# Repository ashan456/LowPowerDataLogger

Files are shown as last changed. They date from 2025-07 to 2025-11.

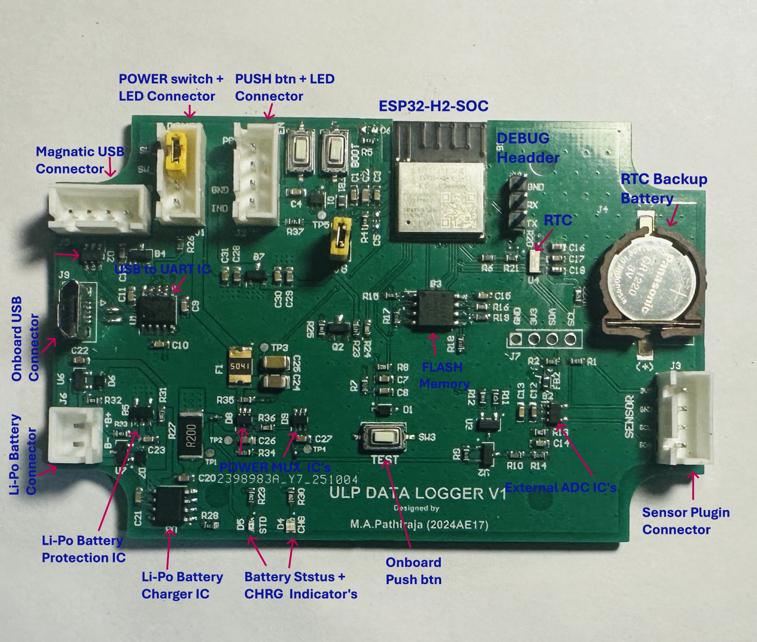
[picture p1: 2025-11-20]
Hardware_Design/Images/Prototype/New folder/PCB Marked.JPG

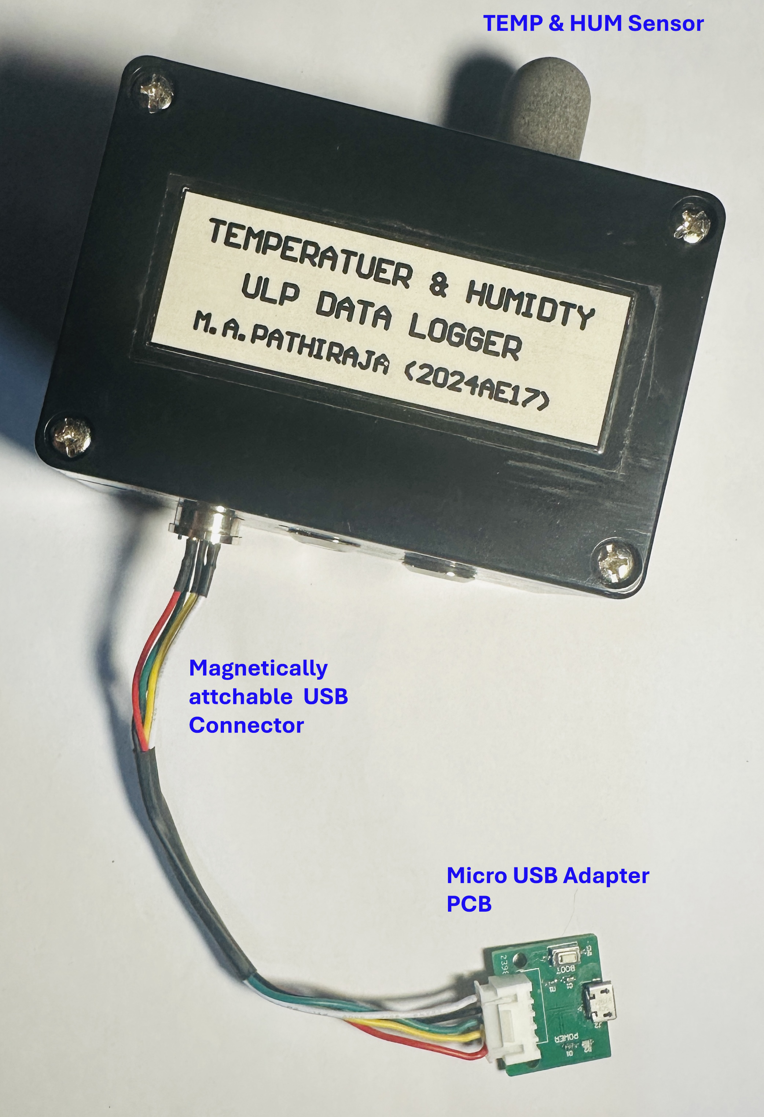
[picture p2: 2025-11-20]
Hardware_Design/Images/Prototype/New folder/Overview.png

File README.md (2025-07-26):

# LowPowerDataLogger
Development of an Ultralow-Power, Battery-Operated Data Logger, specifically tailored for long-term outdoor temperature monitoring in field experiments. 

1.	Introduction

A data logger is an electronic device designed to record measurements over time, storing them for later analysis. This project focuses on the Development of an Ultralow-Power, Battery-Operated Data Logger, specifically tailored for long-term outdoor temperature monitoring in field experiments. By leveraging energy-efficient microcontrollers, precision temperature sensors, and optimized power-management techniques such as deep-sleep modes, lower clock speeds, and low-leakage voltage regulators, the system achieves exceptionally low quiescent currents. Powered by a compact rechargeable or non-rechargeable battery pack and enhanced with a smart power-budget algorithm, the logger can operate autonomously for months without human intervention. Its rugged enclosure, waterproof sealing, and minimal maintenance requirements make it ideal for remote deployments in harsh environments.

2.	Targets

The main targets to be achieved to complete the project are,
• Accurately measure and record ambient temperature.
• Measure and record relative humidity.
• Operate autonomously for at least one month on a single battery charge.
• Buffer and organize time-stamped data in non-volatile local storage.
• Monitor battery voltage and gracefully shut down before depletion.
• Withstand outdoor conditions with a waterproof, rugged enclosure.

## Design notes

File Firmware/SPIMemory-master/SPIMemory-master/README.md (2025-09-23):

# SPIMemory  







## Arduino library for Flash & FRAM Memory Chips (SPI based only)
<sup> Download the latest stable release from [here](https://github.com/Marzogh/SPIMemory/releases/latest). Please report any bugs in [issues](https://github.com/Marzogh/SPIMemory/issues/new).</sup>

This Arduino library is for use with flash and FRAM memory chips that communicate using the SPI protocol. In its current form it supports identifying the flash/FRAM chip and its various features; automatic address allocation and management; writing and reading a number of different types of data, ranging from 8-bit to 32-bit (signed and unsigned) values, floats, Strings, arrays of bytes/chars and structs to and from various locations; sector, block and chip erase; and powering down for low power operation.

<hr>

### IDE Compatibility (actually tested with)

- Arduino IDE v1.5.x
- Arduino IDE v1.6.x
- Arduino IDE v1.8.x

<hr>

### Platform compatibility

| Micro controllers | Dev boards tested with | Notes |
| --- | --- | ----- |
| ATmega328P | Arduino Uno, Arduino Micro, <br> Arduino Fio, Arduino Nano | - |
| ATmega32u4 | Arduino Leonardo, Arduino Fio v3 | - |
| ATmega2560 | Arduino Mega | - |
| ATSAMD21G18 (ARM Cortex M0+) | Adafruit Feather M0, <br> Adafruit Feather M0 Express, <br> Adafruit ItsyBitsy M0 Express | - |
| AT91SAM3X8E (ARM Cortex M3) | Arduino Due | - |
| nRF52832 (ARM Cortex M4F) | Adafruit nRF52 Feather | - |
| ATSAMD51J19 (ARM Cortex M4) | Adafruit Metro M4 | - |
| STM32F091RCT6 | Nucleo-F091RC | |
| STM32L0 | Nucleo-L031K6 | |
| ESP8266 | Adafruit ESP8266 Feather, <br> Sparkfun ESP8266 Thing | - |
| ESP32 | Adafruit ESP32 Feather, <br> Sparkfun ESP32 Thing | Onboard flash memory. Refer to footnote<sup>£</sup> below. |
| Simblee | Sparkfun Simblee | - |

<sup>£ </sup><sub> ESP32 boards usually have an SPI Flash already attached to their default SS pin, so the user has to explicitly declare the `ChipSelect` pin being used with the constructor</sub>

<hr>

### Flash memory compatibility - Actually tested with

| Manufacturer | Flash IC | Notes |
| --- | --- | ----- |
| Winbond | W25Q16BV <br> W25Q64FV <br> W25Q64JV <br> W25Q80BV <br> W25Q256FV | Should work with the W25QXXXBV, W25QXXXFV & <br> W25QXXXJV families |
| Microchip | SST25VF064C <br> SST26VF016B <br> SST26VF032B <br> SST26VF064B | Should work with the SST25 & SST26 families |
| Cypress/Spansion | S25FL032P <br> S25FL116K <br> S25FL127S | Should work with the S25FL family |
| ON Semiconductor | LE25U40CMC |  |
| AMIC| A25L512A0 |  |
| Micron| M25P40 |  |
| Adesto| AT25SF041 |  |
| Macronix| MX25L4005 <br> MX25L4005 |  |
| Giga devices| GD25Q16C | (Used on the Adafruit ItsyBitsy M0 Express) |

##### Should work with any flash memory that is compatible with the SFDP standard as defined in JESD216B

<hr>

### FRAM memory compatibility - Actually tested with

| Manufacturer | Flash IC | Notes |
| --- | --- | ----- |
| Cypress/Spansion | FM25W256 | Should work with the FM25W family |

<hr>

### Installation

#### Option 1
- Open the Arduino IDE.
- Go to Sketch > Include Library > Manage libraries.
- Search for SPIMemory.
- Install the latest version.

#### Option 2
- Click on the 'Clone or download' button above the list of files on this <a href = "https://github.com/Marzogh/SPIMemory/tree/master"> page </a>.
- Select Download ZIP. A .zip file will download to your computer.
- Unzip the archive and rename resulting folder to 'SPIMemory'
- Move the folder to your libraries folder (~/sketches/libraries)

### Usage

#### SPIFlash

- The library is called by declaring the```SPIFlash flash(csPin*)``` constructor where 'flash' can be replaced by a user constructor of choice and 'csPin' is the Chip Select pin for the flash module.

    <sub>* Optional. Do not include csPin if using the default slave select pin for your board.</sub>
- Every version of the library >= v3.0.0 supports the ability to use any of multiple SPI interfaces (if your micro-controller supports them). Switching to use another SPI interface is done by calling ```SPIFlash flash(csPin, &SPI1);``` (or &SPI2 and so on), instead of ```SPIFlash flash(csPin)```.

    <sub>* NOTE: This is currently only supported on the SAMD and STM32 architectures.</sub>
- An alternate version ```SPIFlash flash (SPIPinsArray)``` of the constructor can be used (only with ESP32 board as of now) to enable the use of custom SPI pins. ```SPIPinsArray``` has to be a 4 element array containing the custom SPI pin numbers (as signed integers - int8_t) in the following order - sck, miso, mosi, ss.
- Also make sure to include ```flash.begin(CHIPSIZE*)``` in ```void setup()```. This enables the library to detect the type of flash chip installed and load the right parameters.

    <sub>* Optional</sub>

##### Note on SFDP discovery
As of v3.2.1, SFDP parameter discovery is an user controlled option. To get the library to work with SFDP compatible flash memory chips that are not officially supported by the library, the user must uncomment '//#define USES_SFDP' in 'SPIMemory.h'.

##### Notes on Address overflow and Error checking
- The library has Address overflow enabled by default - i.e. if the last address read/written from/to,  in any function, is 0xFFFFF then, the next address read/written from/to is 0x00000. This can be disabled by uncommenting ```#define DISABLEOVERFLOW``` in SPIMemory.h. (Address overflow only works for Read / Write functions. Erase functions erase only a set number of blocks/sectors irrespective of overflow.)

- All write functions have Error checking turned on by default - i.e. every byte written to the flash memory will be checked against the data stored on the Arduino. Users who require greater write speeds can disable this function by setting an optional last 'errorCheck' argument in any write function to NOERRCHK - For eg. call the function ```writeByte(address, *data_buffer, NOERRCHK)``` instead of ```writeByte(address, *data_buffer)```.

#### SPIFram <sup>^</sup>

- The library is called by declaring the```SPIFram fram(csPin*)``` constructor where 'fram' can be replaced by a user constructor of choice and 'csPin' is the Chip Select pin for the fram module.

    <sub>* Optional. Do not include csPin if using the default slave select pin for your board.</sub>
- Every version of the library >= v3.0.0 supports the ability to use any of multiple SPI interfaces (if your micro-controller supports them). Switching to use another SPI interface is done by calling ```SPIFram fram(csPin, &SPI1);``` (or &SPI2 and so on), instead of ```SPIFram fram(csPin)```.

    <sub>* NOTE: This is currently only officially supported on the SAMD and STM32 architectures.</sub>
- Also make sure to include ```fram.begin(CHIPSIZE*)``` in ```void setup()```. This enables the library to detect the type of fram chip installed and load the right parameters.

<sup>^</sup> <sub> Currently in BETA. The methods in SPIFram are not final and subject to change over the next few revisions.</sub>

The library enables the following functions:
<hr>

#### Non-Read/Write functions
<hr>

###### `begin(_chipsize)`

###### `setClock(clockSpeed)`

###### `error(_verbosity)`

###### `getManID()`

###### `getJEDECID()`

###### `getUniqueID()`

###### `getAddress(sizeOfData)`

###### `sizeofStr()`

###### `getCapacity()`

###### `getMaxPage()`

###### `functionRunTime()`

<hr>

##### Read commands
<hr>
<sub>
All read commands take a last boolean argument 'fastRead'. This argument defaults to FALSE, but when set to TRUE carries out the Fast Read instruction so data can be read at up to the memory's maximum frequency.
</sub>

<sub>
All read commands only take a 32-bit address variable instead of the optional 16-bit page number & 8-bit offset variables in previous versions of the library (< v3.0.0)
</sub>

###### `readAnything(address, value)`

###### `readByte(address)`

###### `readChar(address)`

###### `readWord(address)`

###### `readShort(address)`

###### `readULong(address)`

###### `readLong(address)`

###### `readFloat(address)`

###### `readStr(address, outputStr)`

###### `readAnything(address, value)`
<hr>

##### Write commands
<hr>
<sub>
All write commands take a boolean last argument 'errorCheck'. This argument defaults to TRUE, but when set to FALSE will more than double the writing speed. This however comes at the cost of checking for writing errors. Use with care.
</sub>

<sub> All write commands only take a 32-bit address variable instead of the optional 16-bit page number & 8-bit offset variables in previous versions of the library (< v3.0.0) </sub>

###### `writeByte(address, data)`

###### `writeChar(address, data)`

###### `writeWord(address, data)`

###### `writeShort(address, data)`

###### `writeULong(address, data)`

###### `writeLong(address, data)`

###### `writeFloat(address, data)`

###### `writeStr(address, data)`

###### `writeAnything(address, value)`

<hr>

##### Continuous read/write commands
<sub>
All write commands take a boolean last argument 'errorCheck'. This argument defaults to TRUE, but when set to FALSE will more than double the writing speed. This however comes at the cost of checking for writing errors. Use with care.
</sub>
<hr>

###### `readByteArray(address, *data_buffer, bufferSize)`

###### `writeByteArray(address, *data_buffer, bufferSize)`

###### `readCharArray(address, *data_buffer, bufferSize)`

###### `writeCharArray(address, *data_buffer, bufferSize)`

<hr>

##### Erase commands
<sub>
All erase commands only take a 32-bit address variable instead of the optional 16-bit page number & 8-bit offset variables in previous versions of the library (< v3.0.0)
</sub>
<hr>

###### `eraseSector(address)`

###### `eraseBlock32K(address)`

###### `eraseBlock64K(address)`

###### `eraseChip()`

###### `eraseSection(address, sizeOfData)`

<hr>

##### Suspend/Resume commands
<hr>

###### `suspendProg()`

###### `resumeProg()`
<hr>

##### Power operation commands
<hr>

###### `powerDown()`

###### `powerUp()`

<hr>

##### Error codes explained

Note: If you are unable to fix the error/s, please raise an issue [here](http://www.github.com/Marzogh/SPIMemory/issues) with the details of your flash chip and what you were doing when this error occurred. **Please follow the issue template that show up at the link**

| Error code  | Explanation |
| :---: | --- |
| **0x00** | Function executed successfully |
| **0x01** | `*constructor_of_choice*.begin()` was not called in `void setup()` |
| **0x02** | Unable to identify chip. <br> Is this chip officially supported? |
| **0x03** | Unable to identify capacity. <br> Is this chip officially supported? <br> If not, please define a `CAPACITY` constant and include it in `flash.begin(CAPACITY)`. |
| **0x04** | Chip is busy. Make sure all pins have been connected properly. |
| **0x05** | Page overflow has been disabled and the address called exceeds the memory |
| **0x06** | Unable to Enable Writing to chip. <br> Please make sure the HOLD & WRITEPROTECT pins are pulled up to VCC. |
| **0x07** | This sector already contains data. <br> Please make sure the sectors being written to are erased. |
| **0x08** | You are running low on RAM. <br> Please optimise your code for better RAM usage |
| **0x09** | Unable to suspend/resume operation. <br> Please raise an issue. |
| **0x0A** | Write Function has failed errorcheck. <br> Please raise an issue. |
| **0x0B** | Check your wiring. Flash chip is non-responsive. |
| **0x0C** | This function is not supported by the memory hardware. |
| **0x0D** | Unable to enable 4-byte addressing. <br> Please raise an issue. |
| **0x0E** | Unable to disable 4-byte addressing. <br> Please raise an issue. |
| **0x0F** | The chip is currently powered down. |
| **0x10** | The Flash chip does not support SFDP. |
| **0x11** | Unable to read Erase Parameters from chip. <br> Reverting to library defaults. |
| **0x12** | Unable to read erase times from flash memory. <br> Reverting to library defaults. |
| **0x13** | Unable to read program times from flash memory. <br> Reverting to library defaults. |
| **0x14** | No Chip Select pin defined in the custom SPI Array. <br> Refer to section about Constructor for information on how to use custom SPI pins. |
| **0xFE** | Unknown error. <br> Please raise an issue. |

<hr>

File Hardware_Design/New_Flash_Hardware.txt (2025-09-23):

WP,HOLD short - Pull to  High via 10K
CS - Pull to  High via 10K
CLK - Pull Down via 100K
DI -  Pull Down via 100K
DO -  Pull Down via 100K

battery voltage resitiro devider - Replace with ulp ADC

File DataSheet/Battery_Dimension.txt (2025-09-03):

Length = 50mm
Width = 34mm
Height = 7 mm

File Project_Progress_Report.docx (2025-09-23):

# Development of an ultralow-power battery-operated data logger

Project Progress Report –

## Hardware

• Component Sourcing: 98%

• Ultra Low Battery Hardware: 100% (Complete)

• Working Prototype: 100% (Complete)

• PCB Design: 10%

## Firmware

• Accurate Temp/Humidity Measurement: 100% (Complete)

• Data Storage on Flash (Little FS): 100% (Complete)

• Low Power Sleep Mode (4-7uA sleep, 16-22uA active): 100% (Complete)

• Data Retrieval: 100% (Complete)

• Device Config Without Reflash: 50%

• Fail Safe (RTC/Watchdog/Battery-Based Interval): 20%

Finalized Block Diagram –

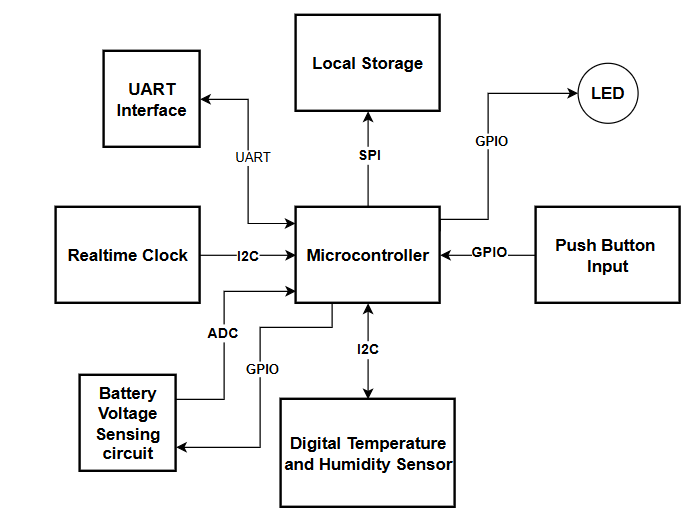
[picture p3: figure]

Figure 1: Block Diagram of the System

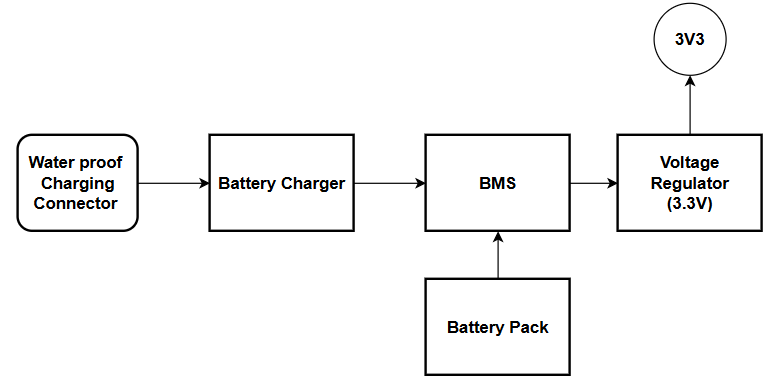
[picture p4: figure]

Figure 2: Block Diagram of the power supply

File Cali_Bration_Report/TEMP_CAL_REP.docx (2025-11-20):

Temperature and Humidity Sensor Calibration

The temperature calibration of the SHT45 sensor was performed at an ISO/IEC 17025 accredited laboratory (IMC, Sri Lanka). Five calibration points were evaluated across the operating range of the sensor. The reference thermometer uncertainty is incorporated into the expanded uncertainty reported by the lab.

- Device Under Test (DUT): Temperature and Humidity Logger (SHT45 Sensos)
- Reference Instrument: Digital thermometer with Pt1000 sensor (Reg No:(7424)362-0191A)
- Measurement Range: Temperature :10°C to 50°C , Humidity: 55.00 %RH and 72.00 %RH

Measurement Data (Provided by Laboratory):

i)Temperature Measurement

Reference Temperature (°C) | Device Reading (°C) | Correction (°C) | Expanded Uncertainty, U (°C)
9.79 | 10.33 | −0.54 | ±0.20
19.60 | 20.06 | −0.46 | ±0.20
29.67 | 29.91 | −0.24 | ±0.20
39.90 | 40.35 | −0.45 | ±0.20
49.89 | 50.28 | −0.39 | ±0.20

ii) Relative Humidity Measurement

Reference Humidity (%) | Device Reading (%) | Correction (%) | Expanded Uncertainty, U (%)
55.00 | 53.21 | 1.79 | ±3
72.00 | 73.15 | -1.15 | ±3

i) Temperature calibration

A linear regression was performed to relate Device temperature reading to true reference temperature,

Performed linear regression to model:

T_(Corrected) =m ×T_(device) +b

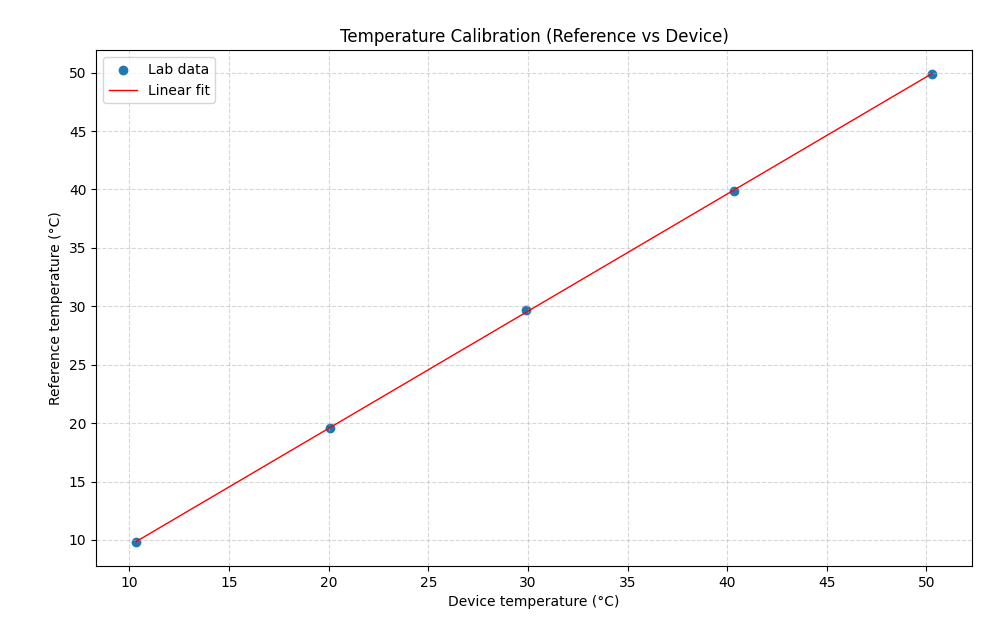
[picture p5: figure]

Best-fit parameters:

- Slope (a): 1.00302
- Offset (b): -0.5073 °C
- Coefficient of determination (R²): 0.9999

Residual statistics

- Mean residual: 0 °C
- Standard deviation: 0.101167 °C
- Maximum absolute residual: 0.176835 °C

Uncertainty Calculation

The lab guarantees the reference temperature is correct within ±0.20 °C with 95% confidence. [multiplying the combined standard uncertainty by a coverage factor k = 2]

Therefore, Lab Reference standard uncertainty = 0.10°C

Calibration model Uncertainty (S.D of residuals) = 0.101167 °C

The Lab reference uncertainty and model fitting uncertainty are independent.

Combine them using root-sum-of-squares (RSS):

u_c =√(u_(lab)^2 +u_(modle)^2)

Where, u_(lab) = 0.1 °C , u_(modle) =0.101167 °C

Substitute values:
u_c =0.1414 °C

Therefore, uncertainty expanded (k=2 for 95% confidence) U=2 ×0.1414 °C=0.2828°C

Fitted model with uncertainty:

T_(Corrected) (°C)=(1.00302 ×T_(device) (°C)-0.5073 ) ±0.28°C

ii) Relative Humidity calibration

The accredited laboratory provided only two calibration points,

Since only two points were provided, a 2-point linear calibration was derived as ,

RH_(Corrected) =m ×RH_(device) +b

The slope m and intercept b were calculated directly using,

m=(R_(2-) R_1)/(D_2 -D_1)=0.8525

b=R_1 -m×D_1 =9.6354

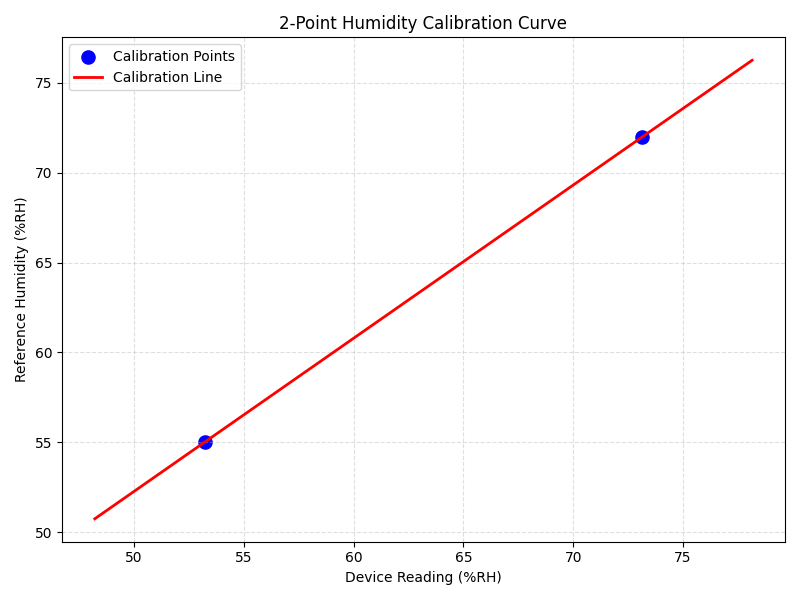
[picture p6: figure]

Uncertainty Calculation

The lab guarantees the reference relative humidity is correct within ±3 %RH with 95% confidence. [multiplying the combined standard uncertainty by a coverage factor k = 2]

Therefore, Lab Reference standard uncertainty = 1.5 % RH

The fitted model itself contributes no statistically estimable additional uncertainty (u_fit ≈ 0 %RH, artefact of 2-point line).

Therefore , Calibration model Uncertainty (S.D of residuals) = 0 % RH

The Lab reference uncertainty and model fitting uncertainty are independent.

Combine them using root-sum-of-squares (RSS):

u_c =√(u_(lab)^2 +u_(modle)^2)

Where, u_(lab) = 1.5 % RH , u_(modle) =0 % RH

Substitute values:
u_c =1.5 % RH

Therefore, uncertainty expanded (k=2 for 95% confidence) U=2 ×1.5 % RH=3 % RH

Fitted model with uncertainty:

RH_(Corrected) (%RH)=(0.8525×RH_(device) (%RH)+9.6354) ±3% RH

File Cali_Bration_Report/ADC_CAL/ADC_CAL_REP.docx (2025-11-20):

Battery Voltage Measurement - ADC Calibration

The MCP3021 (12-bit) ADC was used to measure the battery voltage in the custom ESP32-H2 data logger hardware.

- Device Under Test (DUT): Custom PCB with ESP32-H2 and MCP3021 ADC
- Reference Instrument: Digital Multimeter (DMM, ±25mV at range (9.999V))
- Voltage Source: Bench DC power supply
- Measurement Range: 3300–4300 mV

Measurement Data:

Multiple voltages measured (Supplied from Bench power supply in range 3.3V to 4.3V) simultaneously by the DMM and ADC (uncalibrated firmware output).

Table 1.1: Reference Voltage and ADC computed Voltage in mV

Reference Voltage (mV) [±25 mV] | ADC Measurement (mV)
3302 | 3317
3401 | 3409
3501 | 3506
3601 | 3606
3701 | 3703
3804 | 3802
3903 | 3899
4001 | 3999
4102 | 4098
4201 | 4201
4304 | 4294

Linear Regression Model

A linear model was fitted to relate the ADC reading (input) to the true reference voltage,

V_(Calibrated) =a ×V_(ADC) +b

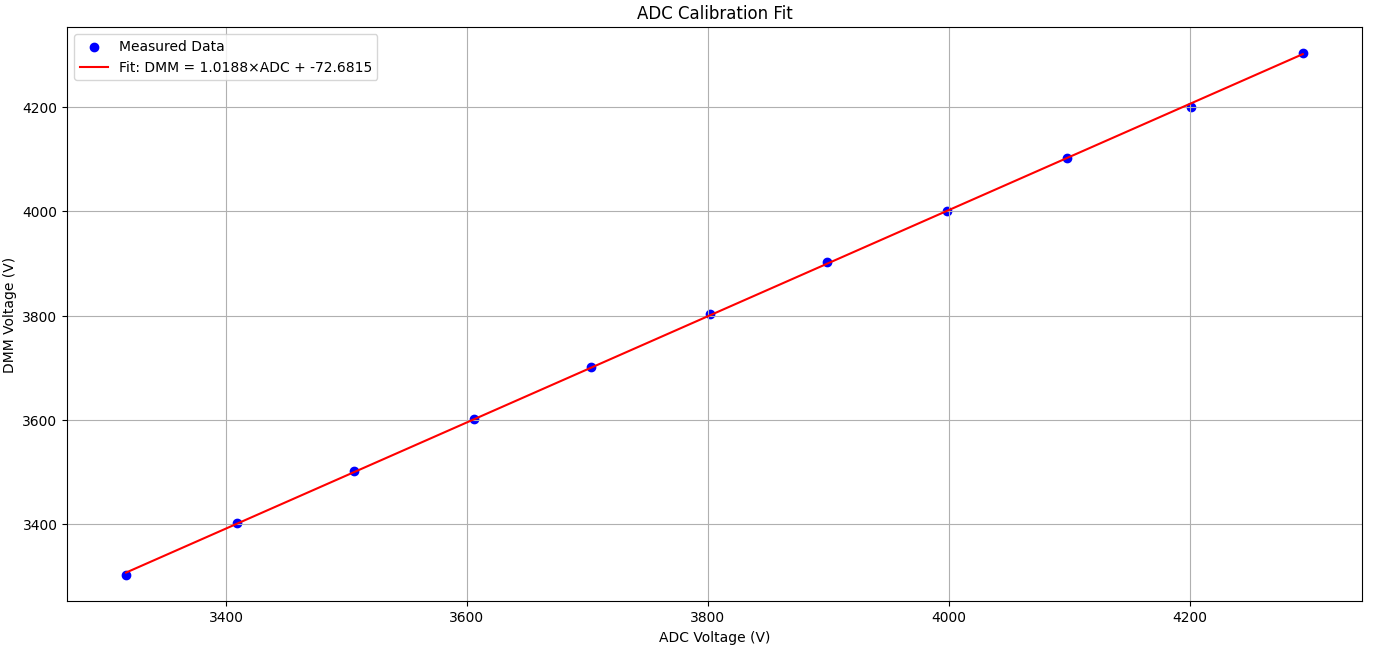
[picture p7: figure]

Best-fit parameters:

- Slope (a): 1.0188
- Offset (b): –72.6815 mV
- Coefficient of determination (R²): 0.999917

Residual statistics

- Mean residual: ≈ 4.5×10^(-13) mV → effectively 0 mV
- Standard deviation: 2.89 mV
- Maximum absolute residual: 6.3 mV (at 4201 mV point)

Note: -

After calibration, the ADC readings follow the model with max error ≈ ±6.3 mV, but the absolute accuracy is limited by the DMM’s ±25 mV.

Fitted model with uncertainty:

V_(Calibrated) (mV)=1.0188 ×V_(ADC) (mV)-72.6815 ±25 mV

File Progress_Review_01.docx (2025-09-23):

Hardware:

- Component Sourcing - 90%
- Ultra Low Battery Powered Hardware Construction – 100% - Completed
- Working Prototype – 100% Completed

Firmware :

- Measure Temperature and Humidity accurately – 100%
- Store Data on Local Storage (Uses Little FS File system on Flash memory) – 100%
- Low power sleep Mode (Timer Interrupt) – 100% ( Sleep :- 4 - 7uA) and (Active :- 16 - 22 uA average)
- Retrieve stored data from the device – 100%
- Device Configuration without re-flashing firmware – 50%
- Fail safe (RTC not worked, Watchdog , Change interval based on battery power) – 20%

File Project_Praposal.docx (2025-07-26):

Development of an ultralow-power battery-operated data logger

M.A. Pathiraja (2024AE17)

2025.07.26

# 1. Introduction

Accurate environmental monitoring underpins climate science, ecological investigation, and agricultural optimization; however, extant data‐logging instruments are often prohibitively expensive, necessitate frequent battery replacement, and exhibit limited resilience in adverse outdoor settings. This proposal outlines the Development of an Ultralow-Power, Battery-Operated Data Logger for sustained field deployment. The architecture integrates an energy-efficient microcontroller, a factory-calibrated temperature and humidity sensors, and firmware optimized through deep-sleep operation, clock scaling, and adaptive duty cycling to minimize energy consumption. A smart power-budget algorithm, in concert with either rechargeable (Li-ion) or primary cell chemistries and ultra-low-leakage voltage regulation, facilitates autonomous operation exceeding one month on a single charge. Recorded data are preserved in onboard nonvolatile memory with precise timestamps, while the IP65-rated enclosure with sealed connectors and corrosion-resistant push button to ensure mechanical robustness. Collectively, these design choices yield a maintenance-free, rugged solution for long-term environmental data acquisition in challenging field environments.

# 2. Targets

The main targets to be achieved to complete the project are,

- Accurately measure and record ambient temperature.
- Measure and record relative humidity.
- Operate autonomously for at least one month on a single battery charge.
- Buffer and organize time-stamped data in non-volatile local storage.
- Monitor battery voltage and gracefully shut down before depletion.
- Withstand outdoor conditions with a waterproof, rugged enclosure.

# 3. Methodology

The ultralow-power data logger is predicated on a microcontroller that remains in deep-sleep until awakened by an RTC alarm or timer-interrupt, at which point it acquires temperature and humidity measurements from a factory-calibrated sensor (e.g., AHT2415C) and assesses the battery voltage. Upon wakeup, the device records these time-stamped readings to nonvolatile memory before promptly returning to its low-power state. Quiescent current is minimized using an ultra-low-leakage LDO, while optimized firmware algorithms further reduce active-mode energy consumption. A GPIO-controlled resistor divider, which engages only during voltage measurement to eliminate idle current draw, scales the battery pack voltage for ADC conversion and dynamically adjusts the data-collection interval to extend operational longevity. The push button, status LED and USART interface will be used to allow users to interact with the firmware to change certain settings. The Power is replenished via a waterproof charging interface that accommodates a Li-ion charger and battery-management system (BMS), ensuring cell protection. Collectively, these design features facilitate over more than one month of autonomous, maintenance-free outdoor operation on a single battery charge.


Figure 3.1: Block Diagram of the System


Figure 3.2: Block Diagram of the power supply

MEL 5450: Embedded Systems Project

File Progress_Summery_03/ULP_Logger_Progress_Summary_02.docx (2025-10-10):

Development of an Ultralow-Power Battery-Operated Temperature and Humidity Data Logger

M.A. Pathiraja (2024AE17)

Current Progress

I have developed a compact, ultra-low-power environmental data logger consuming less than 25 µA in deep-sleep mode. It reliably records timestamped temperature and humidity data and can be easily configured, downloaded, and analyzed using a PC tool.

Objectives & Progress

- Logn lasting operation on single battery charge (More than one month) – 100% (Projected more than one year)
- Accurate temperature & humidity logging with timestamps. – 100%
- RTC fail safe mechanism - 100%
- Retrieve data from device to PC – 100%
- Change device configuration without re-flashing the firmware. – 100%
- Outdoor‑ready waterproof design. – 100%
1. Major Achievements
- Low-Power Optimized Prototype – Fully functional hardware designed for ultra-low energy consumption.
- Measured Deep-Sleep Current: ~20.48 µA (verified using Nordic PPK2)
- ULP-Optimized Firmware – Includes deep-sleep mode, RTC-based wake-up, CSV data logging.
- Data Retrieval & Config mode – Download stored data and config device settings via UART configuration interface.
- PC GUI Tool – Supports device configuration, data download and formatting, data visualization and analysis

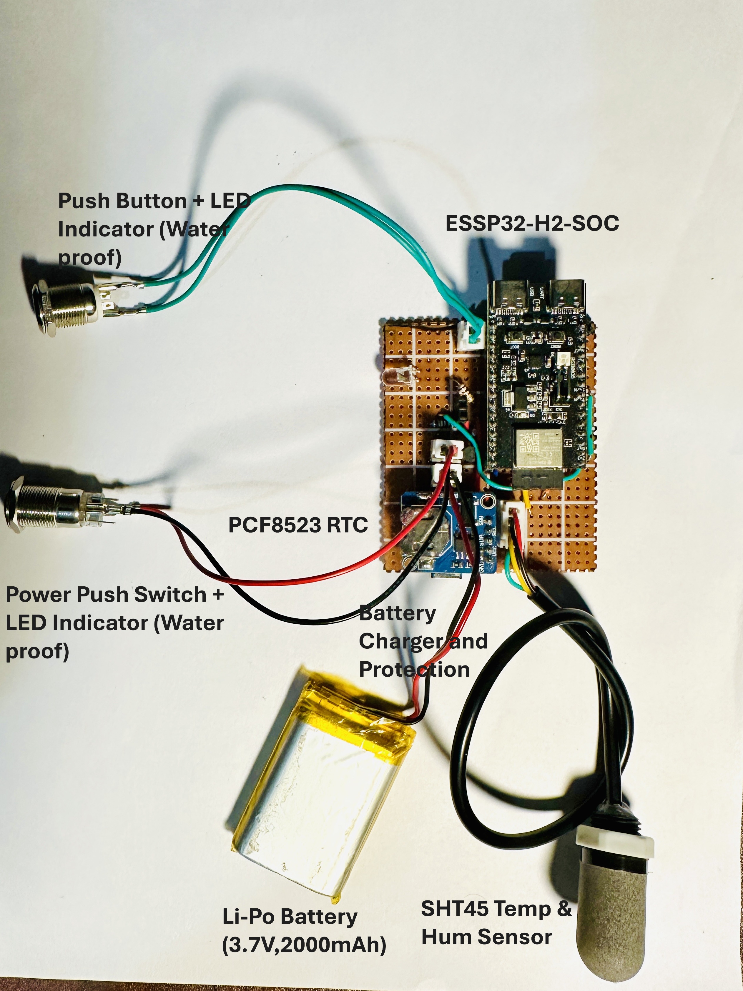
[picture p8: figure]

Figure 1: Current Prototype Without Enclosure

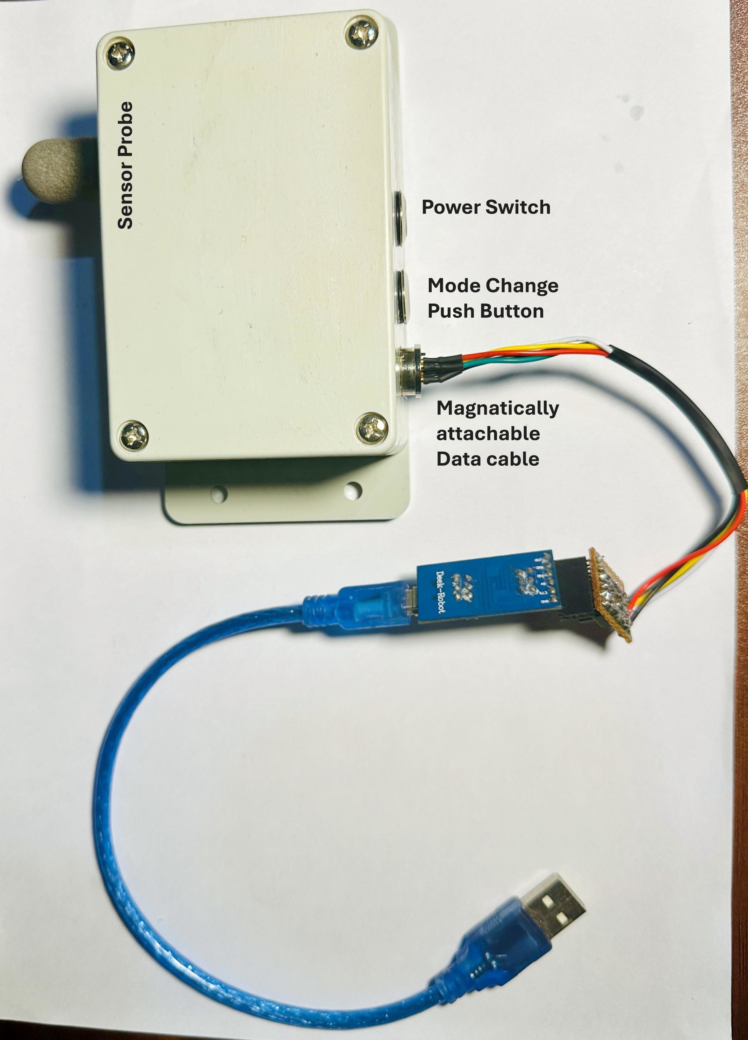
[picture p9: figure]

Figure 2: Assembled Prototype in Enclosure

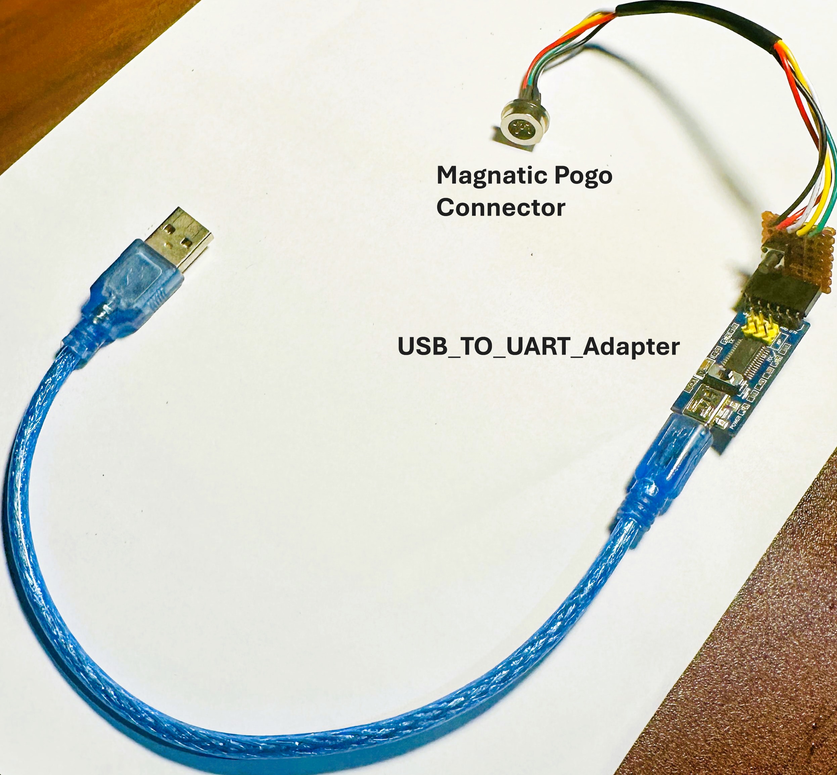
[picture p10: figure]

Figure 3: Magnetically attachable data cable

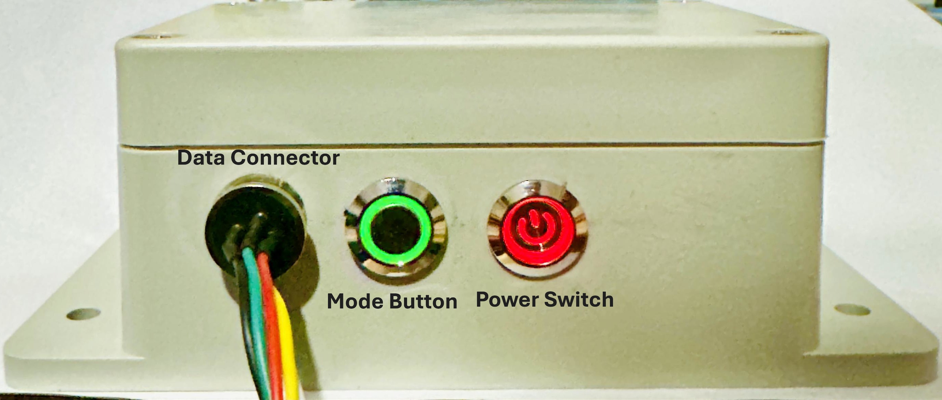
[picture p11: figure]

Figure 4: Prototype Front Panel view (Indicator LED’s ON)

2. Hardware Overview

2.1 Current Hardware Specifications

- MCU: ESP32-H2 (RISC-V) with integrated BLE
- Sensor: SHT45 (Temperature and Humidity)
- RTC: PCF8523 (Version 1)
- Storage: LittleFS (https://docs.espressif.com/projects/esp-idf/en/stable/esp32/api-guides/file-system-considerations.html) file system on internal flash memory SPIFFS partition.
- Power Supply: 3.7 V Li-Po battery with built-in charging and protection circuit
- I/O Interface: Magnetic pogo-pin connector
- Enclosure: IP65-rated waterproof housing

2.2 Planned Hardware Improvements (Already Implemented in final prototype PCB)

- Precision ULP ADC for battery measurement (improves SoC accuracy).
- RV3028 temperature‑compensated RTC (±1 ppm).
- External SPI flash (16 Mbit) for extended logging capacity.
- Dedicated power‑path controller for seamless USB/battery switching.
- Commercial grade PCB design.

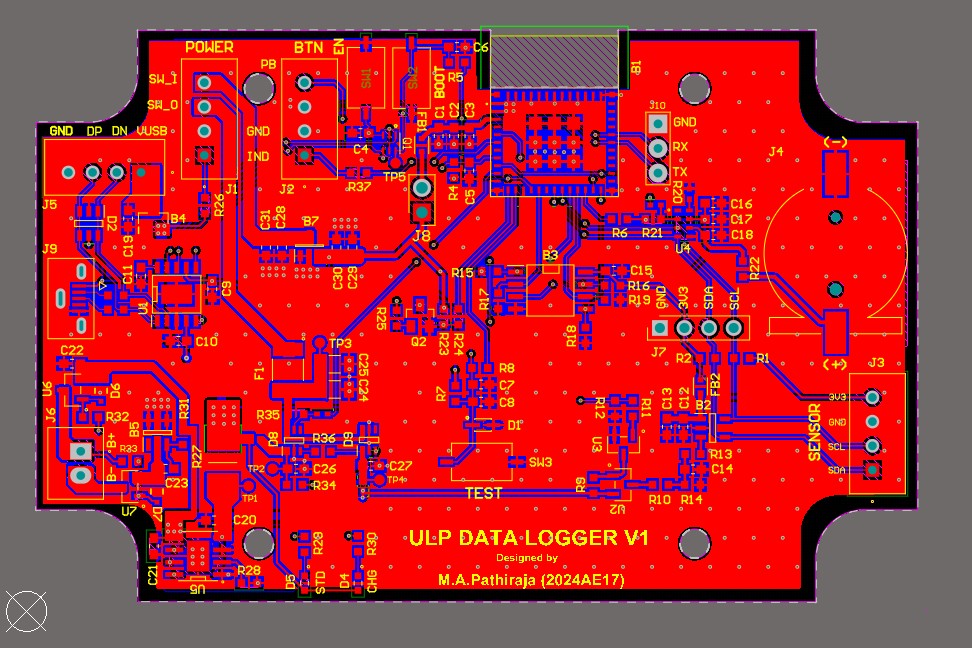
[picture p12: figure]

Figure 5: Datalogger PCB design Layout (with improved hardware features)

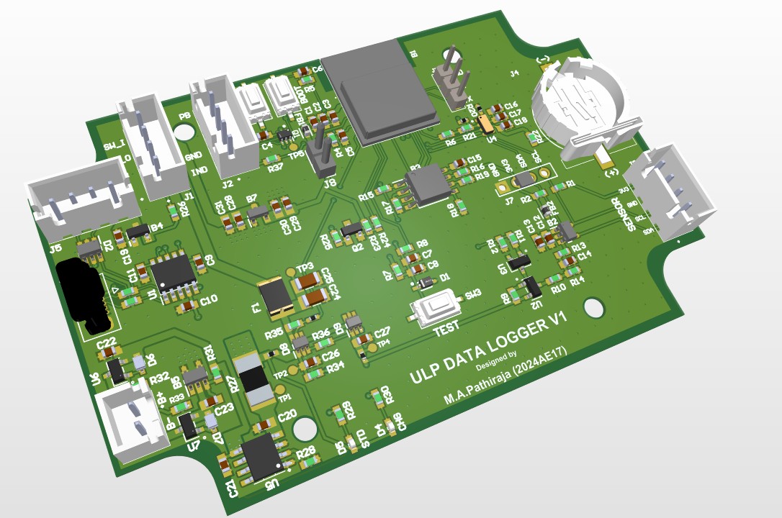
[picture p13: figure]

Figure 6: Datalogger PCB design 3D view

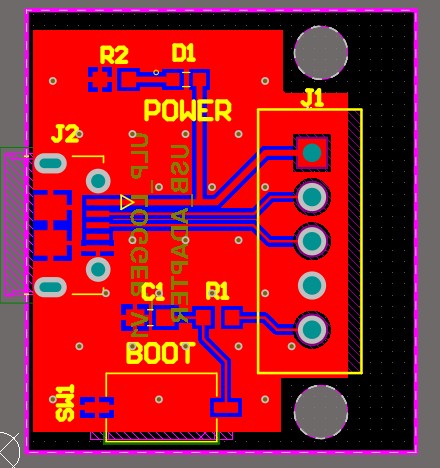
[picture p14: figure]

Figure 7: USB adapter PCB design Layout

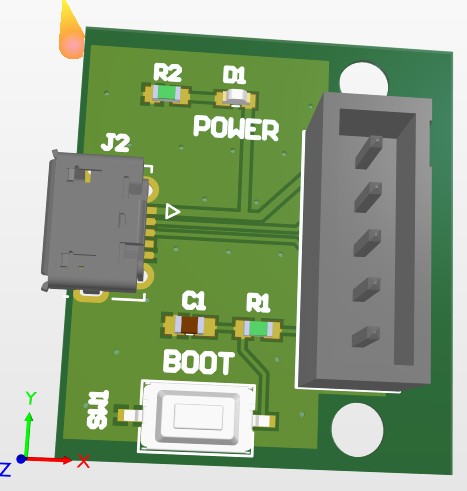
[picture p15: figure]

Figure 8: USB adapter PCB design 3D view

3. Firmware Status & Roadmap

3.1 Current Firmware specifications

- Deep Sleep Operation – Minimizes power consumption during idle periods.
- CSV Logging – Stores timestamped data records in CSV format and create new csv file for each day.
- RTC Fail safe Operation – If RTC failed calculate the time from last record.
- UART Configuration – Allows device setup and parameter adjustment via serial interface.
- Data Retrieval – Easily view stored records and download to PC.
- Persistent Settings – Retains user configurations across power cycles.
- LED Control – Provides visual status indication through programmable LED behavior.

3.2 Planned Firmware Improvements

- BLE Data and Configuration – Enables wireless data transfer and device setup via Bluetooth Low Energy.
- External Flash Storage– Supports continuous data logging combining external flash memory.
- Battery Runtime Estimation and Adaptive Sampling – Adjusts sampling rate for estimating battery capacity.

4. PC GUI Tool

A PC-based GUI tool was developed for easy configuration and analysis of the data logger. It enables users to adjust settings, synchronize the RTC, view live data, and download or manage stored logs. The interface features automatic COM detection and real-time plotting for quick and intuitive operation.

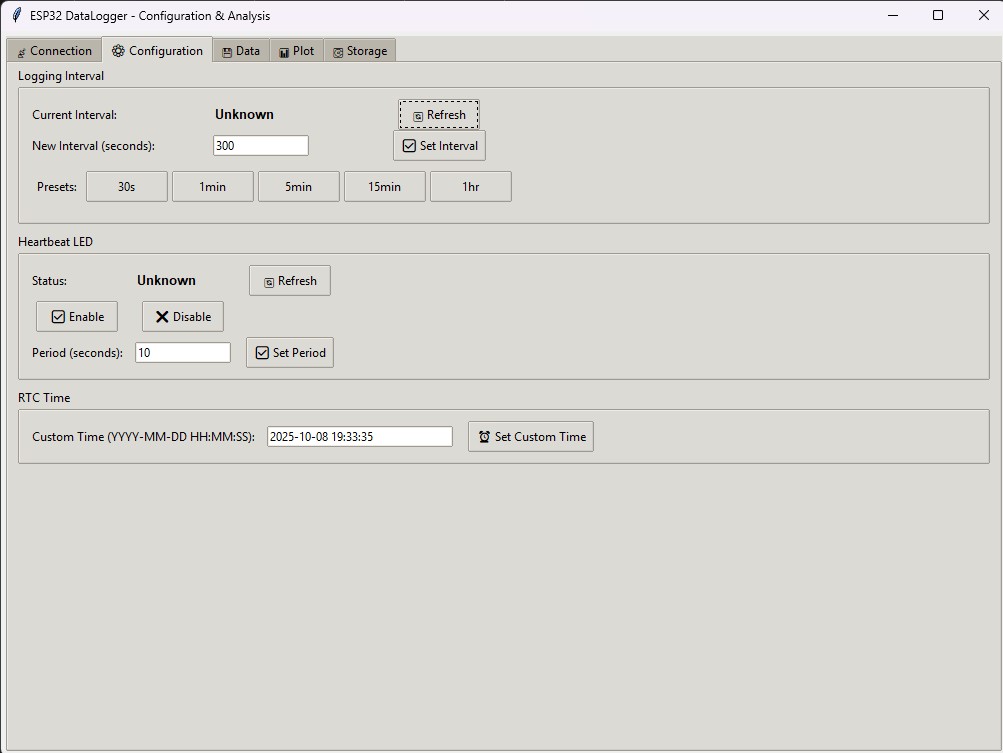
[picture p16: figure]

Figure 9: Connection/Configuration UI

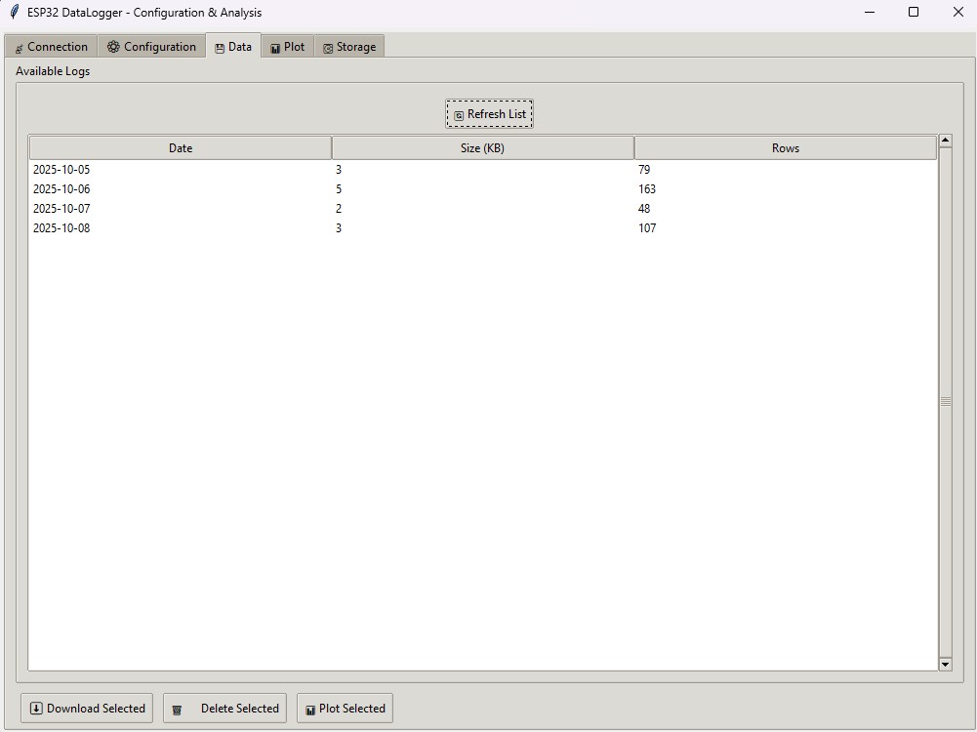
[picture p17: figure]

Figure 10: Data Management UI

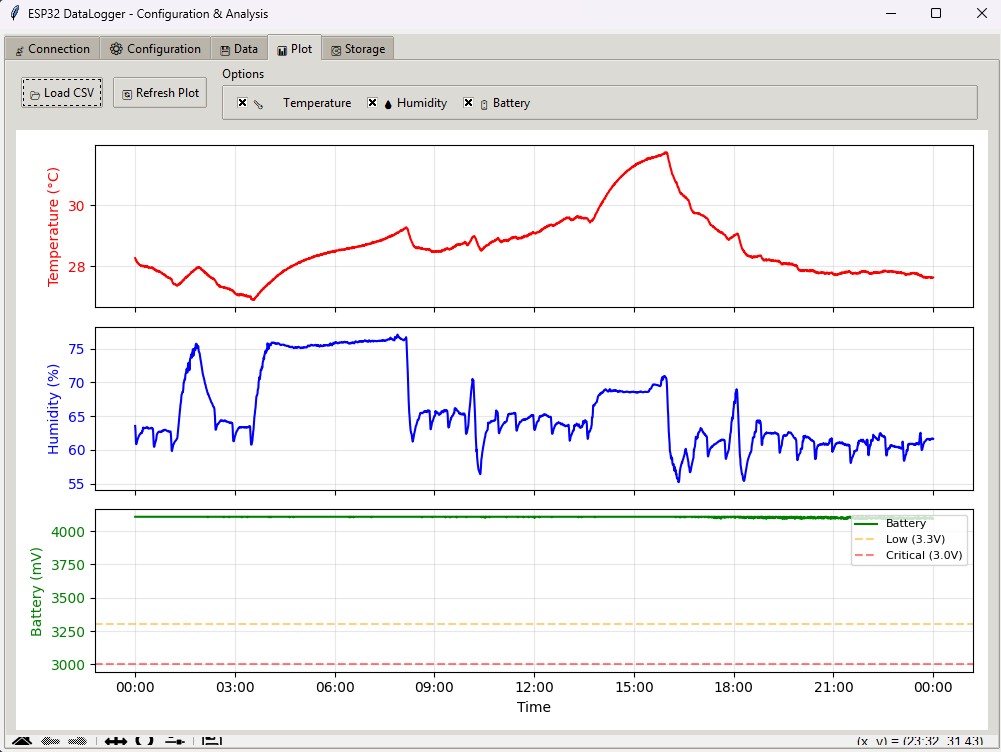
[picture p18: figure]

Figure 11: Visualization (Temp/RH/VBAT)

Those are the implemented GUI Features,

- Automatic COM Port Detection – Identifies connected devices instantly.
- Live Status Monitoring – Displays real-time device activity and connection state.
- Firmware, Battery, and Storage Information – Shows system version, battery level, and memory usage.
- Set Logging Interval – Adjust data recording frequency as needed.
- RTC Synchronization – Sync device time with PC for accurate timestamps.
- LED Control – Enable or disable status LED indication.
- Save Configuration Parameters – Store user-defined settings permanently.
- List and Download Logs – Browse and retrieve recorded data files.
- Format Storage – Clear or reinitialize internal memory.
- Real-Time Plotting – Visualize live sensor data on PC.

5. Power Consumption

Measurement tool: Nordic PPK2 (https://www.nordicsemi.com/Products/Development-hardware/Power-Profiler-Kit-2) (source mode , Voltage = 3.7 V).

- Deep‑sleep: ~20.48 µA (max ~22.28 µA).
- Active logging (1 s every 5 min): average ~8.05 mA across the cycle.

Projected battery life (2000 mAh , 10‑min interval): ≈ 1.4 years (theoretical).

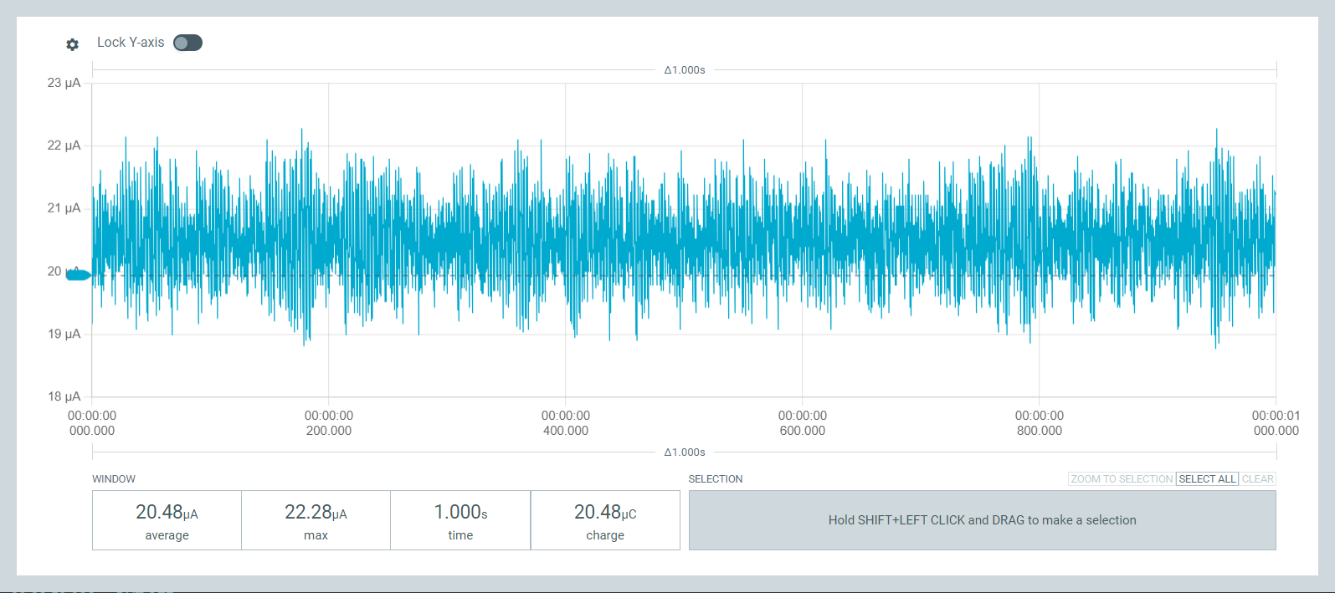
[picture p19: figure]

Figure 12: Deep‑Sleep Current Profile

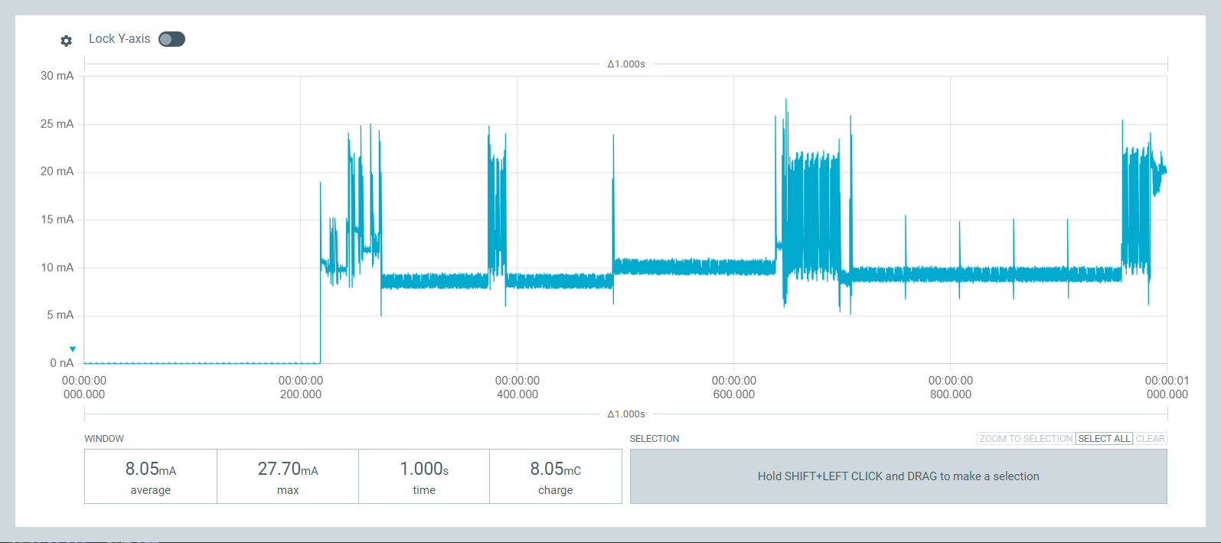
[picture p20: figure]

Figure 13: Active Logging Profile

6. Data Storage & Runtime

- Average record size: ≈ 24 bytes
- One-day CSV (10 min sampling): ≈ 3.5 KB
- LittleFS capacity: ≈ 1.38 MB
- Estimated retention: ≈ 395 days (with 5 % safety margin)
- Maximum possible: ≈ 415 days continuous logging before full

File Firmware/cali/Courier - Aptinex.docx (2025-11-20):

M.A. Pathiraja

Sri Darmadara Road, Hegoda

Rathgama, Galle

Tele: 0775480782

1) Push Power Switch to Down.

2) Green LED will Blink.

3) Connect USB Adapter to PC.

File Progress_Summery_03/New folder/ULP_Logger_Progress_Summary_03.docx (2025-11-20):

Development of an Ultralow-Power Battery-Operated Temperature and Humidity Data Logger

M.A. Pathiraja (2024AE17)

Current Progress

I have developed a compact, ultra-low-power environmental data logger that consumes less than 25 µA in deep-sleep mode. The device reliably records timestamped, calibrated temperature and humidity measurements and supports easy configuration, data download, and analysis through a dedicated PC software tool.

Objectives & Progress

- Long lasting operation on single battery charge (More than one month) – 100% (Projected more than one year)
- Accurate temperature & humidity logging with timestamps. – 100%
- Sensor readings were calibrated – 100%
- Retrieve data from device to PC – 100%
- Change device configuration without re-flashing the firmware. – 100%
- Outdoor‑ready waterproof design. – 100%
1. Major Achievements
- Low-Power Optimized Prototype – Fully functional hardware designed for ultra-low energy consumption.
- Calibrated Sensors – Temperature and Humidity readings were calibrated.
- Ultra-low power Consumption: Measured sleep current (22.28 µA) (verified using Nordic PPK2)
- ULP-Optimized Firmware – Includes deep-sleep mode, RTC-based wake-up, encoded data logging.
- Data Retrieval & Config mode – Download stored data and config device settings via UART configuration interface.
- PC GUI Tool – Supports device configuration, data download and formatting, data visualization and analysis
- Rugged Design - IP65 rated Outdoor‑ready waterproof design.
2. Device Overview


Figure 1: ULP Datalogger TOP view with Magnetic USB adapter

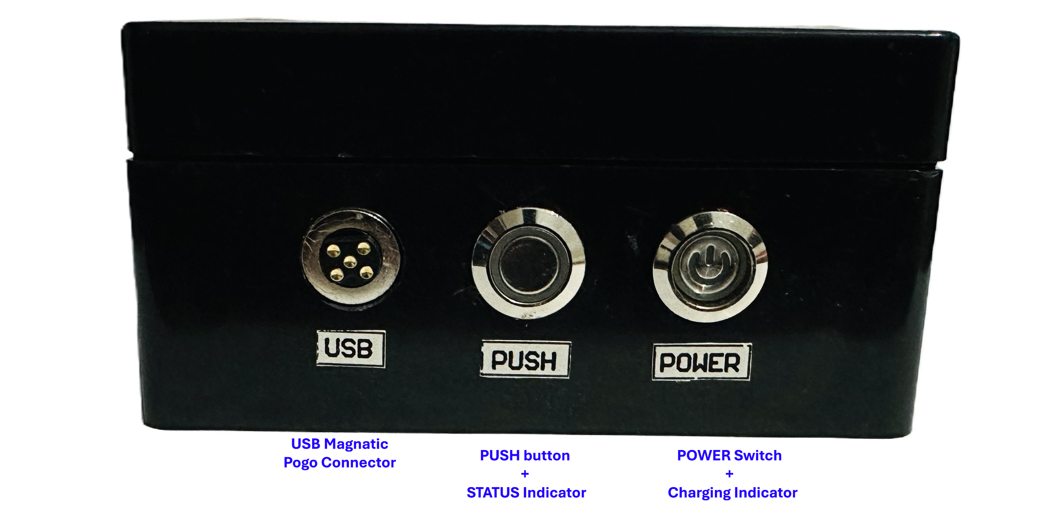
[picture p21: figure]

Figure 2: ULP Datalogger Front Panel

3. Hardware Overview

- MCU: ESP32-H2 (RISC-V) with integrated BLE
- Sensor: SHT45 Temperature and Humidity Sensor. (calibrated)
- RTC: RV3028 temperature‑compensated RTC (±1 ppm).
- Storage: Internal flash (11Mbit) and (16Mbit) external flash.
- Power Supply: 3.7 V Li-Po battery with built-in charging and protection circuit
- I/O Interface: Magnetic pogo-pin connector
- Precision ULP ADC: For accurate battery voltage measurement (Calibrated).
- Enclosure: IP65-rated waterproof housing

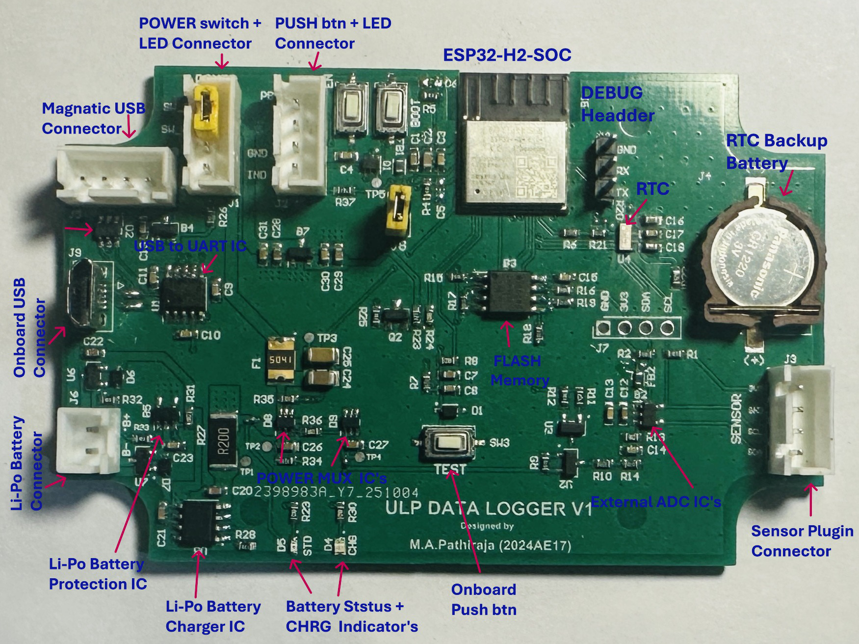
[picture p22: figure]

Figure 3: Datalogger PCB assembled

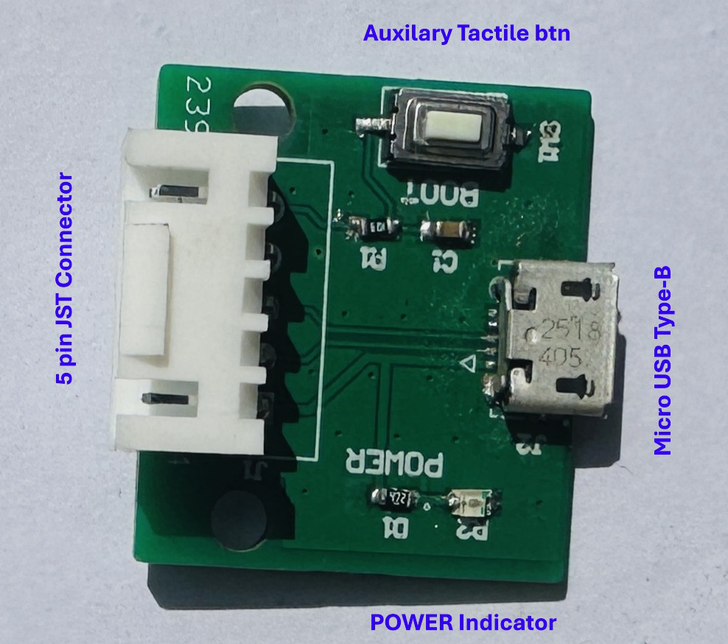
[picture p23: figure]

Figure 4: USB adapter PCB Assembled

4. Firmware specifications
- Deep Sleep Operation – Minimizes power consumption during idle periods.
- Data Logging – Stores timestamped data records in (7-byte) binary format.
- UART Configuration – Allows device setup and parameter adjustment via serial interface.
- Data Retrieval – Easily view stored records and download to PC.
- Persistent Settings – Retains user configurations across power cycles.
- LED Control – Provides visual status indication through programmable LED behavior.

5. PC GUI Tool

A PC-based GUI tool was developed for easy configuration and analysis of the data logger. It enables users to adjust settings, synchronize the RTC, view live data, and download or manage stored logs. The interface features automatic COM detection and real-time plotting for quick and intuitive operation.

Implemented GUI Features,

- Firmware, Battery, and Storage Information – Shows system version, battery level, and memory usage.
- Set Logging Interval – Adjust data recording frequency as needed.
- RTC Synchronization – Sync device time with PC for accurate timestamps.
- Save Configuration Parameters – Store user-defined settings permanently.
- List and Download Logs – Browse and retrieve recorded data files.
- Format Storage – Clear or reinitialize internal memory.
- Real-Time Plotting – Visualize live sensor data on PC.


Figure 5: Connection/Configuration UI


Figure 6: Visualization (Temp/RH/VBAT)

6. Power Consumption

Measurement tool: Nordic PPK2 (https://www.nordicsemi.com/Products/Development-hardware/Power-Profiler-Kit-2) (source mode , Voltage = 3.7 V).

- Deep‑sleep: ~20.48 µA (max ~22.28 µA).
- Active logging (1 s every 5 min): average ~8.05 mA across the cycle.

Projected battery life (2000 mAh , 5‑min interval): ≈ 1 years (theoretical).


Figure 7: Deep‑Sleep Current Profile (Avg sleep current around 20.48 uA)


Figure 8: Active Logging Profile (Avg active current around 8.05 mA)

7. Data Storage & Runtime

- Single record size: ≈ 7 bytes
- One-day (5 min sampling): ≈ 2 KB
- Total Storage capacity: ≈ (1.38 MB + 2MB) = 3.38 MB
- Estimated retention: ≈ 1600 days (with 5 % safety margin)
- Maximum possible: ≈ 360 days continuous logging. (From Single battery Charge)

8. Temperature & Humidity Sensor Calibration

The temperature calibration of the SHT45 sensor was performed at an ISO/IEC 17025 accredited laboratory (IMC, Sri Lanka). Five calibration points were evaluated across the operating range of the sensor. The reference thermometer uncertainty is incorporated into the expanded uncertainty reported by the lab.

- Device Under Test (DUT): Temperature and Humidity Logger (SHT45 Sensos)
- Reference Instrument: Digital thermometer with Pt1000 sensor (Reg No:(7424)362-0191A)
- Measurement Range: Temperature :10°C to 50°C , Humidity: 55.00 %RH and 72.00 %RH

Measurement Data (Provided by Laboratory):

i)Temperature Measurement

Table 8.1: Reference Temperature and Device (Sensor) readings with correction and expanded uncertainty (K=2 , for 95% confidence level)

Reference Temperature (°C) | Device Reading (°C) | Correction (°C) | Expanded Uncertainty, U (°C)
9.79 | 10.33 | −0.54 | ±0.20
19.60 | 20.06 | −0.46 | ±0.20
29.67 | 29.91 | −0.24 | ±0.20
39.90 | 40.35 | −0.45 | ±0.20
49.89 | 50.28 | −0.39 | ±0.20

ii) Relative Humidity Measurement

Table 8.2: Reference Humidity and Device (Sensor) readings with correction and expanded uncertainty (K=2, for 95% confidence level)

Reference Humidity (%) | Device Reading (%) | Correction (%) | Expanded Uncertainty, U (%)
55.00 | 53.21 | 1.79 | ±3
72.00 | 73.15 | -1.15 | ±3

i) Temperature calibration

A linear regression was performed to relate Device temperature reading to true reference temperature,

Performed linear regression to model:

T_(Corrected) =m ×T_(device) +b (01)

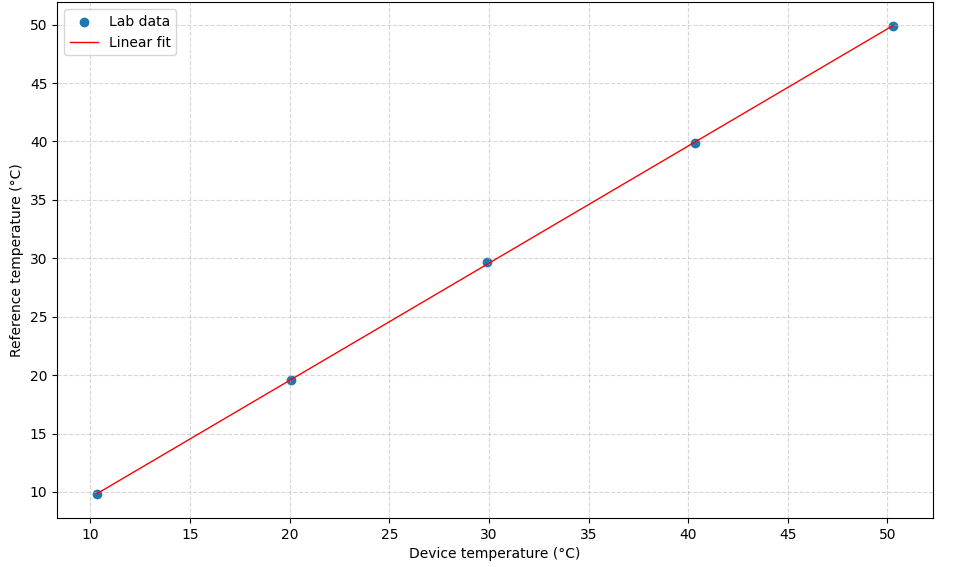
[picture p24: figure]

Figure 9: Calibration Plot Showing Device vs. Reference Temperature with Linear Fit

Best-fit parameters:

- Slope (a): 1.00302
- Offset (b): -0.5073 °C
- Coefficient of determination (R²): 0.9999

Residual statistics

- Mean residual: 0 °C
- Standard deviation: 0.101167 °C
- Maximum absolute residual: 0.176835 °C

Uncertainty Calculation

The lab guarantees the reference temperature is correct within ±0.20 °C with 95% confidence. [multiplying the combined standard uncertainty by a coverage factor k = 2]

Therefore, Lab Reference standard uncertainty = 0.10°C

Calibration model Uncertainty (S.D of residuals) = 0.101167 °C

The Lab reference uncertainty and model fitting uncertainty are independent.

Combine them using root-sum-of-squares (RSS):

(02)

u_c =√(u_(lab)^2 +u_(modle)^2)

Where, u_(lab) = 0.1 °C , u_(modle) =0.101167 °C

Substitute values:
u_c =0.1414 °C

Therefore, uncertainty expanded (k=2 for 95% confidence) U=2 ×0.1414 °C=0.2828°C

Fitted model with uncertainty:

(03)

T_(Corrected) (°C)=(1.00302 ×T_(device) (°C)-0.5073 ) ±0.28°C

ii) Relative Humidity calibration

The accredited laboratory provided only two calibration points,

Since only two points were provided, a 2-point linear calibration was derived as ,

(04)

RH_(Corrected) =m ×RH_(device) +b

The slope m and intercept b were calculated directly using,

(06)

(05)

m=(R_(2-) R_1)/(D_2 -D_1)=0.8525

b=R_1 -m×D_1 =9.6354

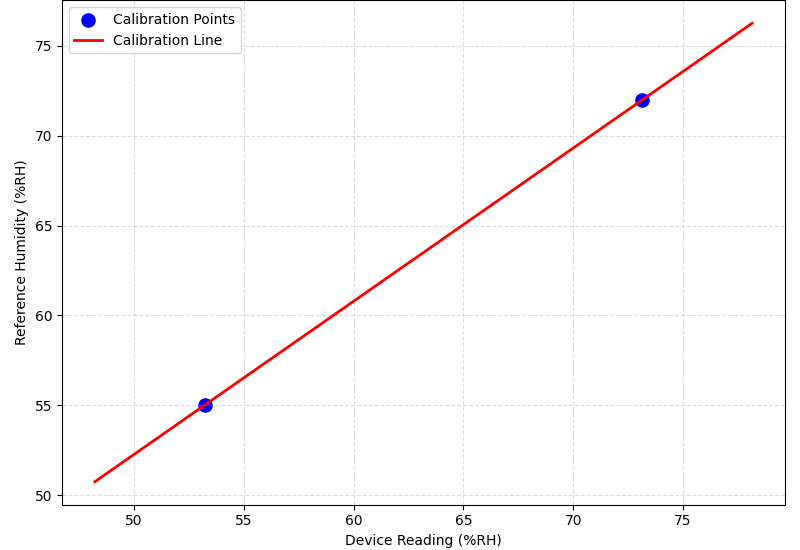
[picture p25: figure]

Figure 10: Two-Point Humidity Calibration Curve Showing Device Readings vs. Reference Relative Humidity with Fitted Linear Model

Uncertainty Calculation

The lab guarantees the reference relative humidity is correct within ±3 %RH with 95% confidence. [multiplying the combined standard uncertainty by a coverage factor k = 2]

Therefore, Lab Reference standard uncertainty = 1.5 % RH

The fitted model itself contributes no statistically estimable additional uncertainty (u_fit ≈ 0 %RH, artefact of 2-point line).

Therefore , Calibration model Uncertainty (S.D of residuals) = 0 % RH

The Lab reference uncertainty and model fitting uncertainty are independent.

Combine them using root-sum-of-squares (RSS):

(07)

u_c =√(u_(lab)^2 +u_(modle)^2)

Where, u_(lab) = 1.5 % RH , u_(modle) =0 % RH

Substitute values:
u_c =1.5 % RH

Therefore, uncertainty expanded (k=2 for 95% confidence) U=2 ×1.5 % RH=3 % RH

Fitted model with uncertainty:

(08)

RH_(Corrected) (%RH)=(0.8525×RH_(device) (%RH)+9.6354) ±3% RH

9. ADC Calibration (Battery Voltage measurement)

The MCP3021 (12-bit) ADC was used to measure the battery voltage in the custom ESP32-H2 data logger hardware.

- Device Under Test (DUT): Custom PCB with ESP32-H2 and MCP3021 ADC
- Reference Instrument: Digital Multimeter (DMM, ±25mV at range (9.999V))
- Voltage Source: Bench DC power supply
- Measurement Range: 3300–4300 mV

Measurement Data:

Multiple voltages measured (Supplied from Bench power supply in range 3.3V to 4.3V) simultaneously by the DMM and ADC (uncalibrated firmware output).

Table 9.2: Reference Voltage and ADC computed Voltage in mV

Reference Voltage (mV) [±25 mV] | ADC Measurement (mV)
3302 | 3317
3401 | 3409
3501 | 3506
3601 | 3606
3701 | 3703
3804 | 3802
3903 | 3899
4001 | 3999
4102 | 4098
4201 | 4201
4304 | 4294

Linear Regression Model

A linear model was fitted to relate the ADC reading (input) to the true reference voltage,

V_(Calibrated) =a ×V_(ADC) +b

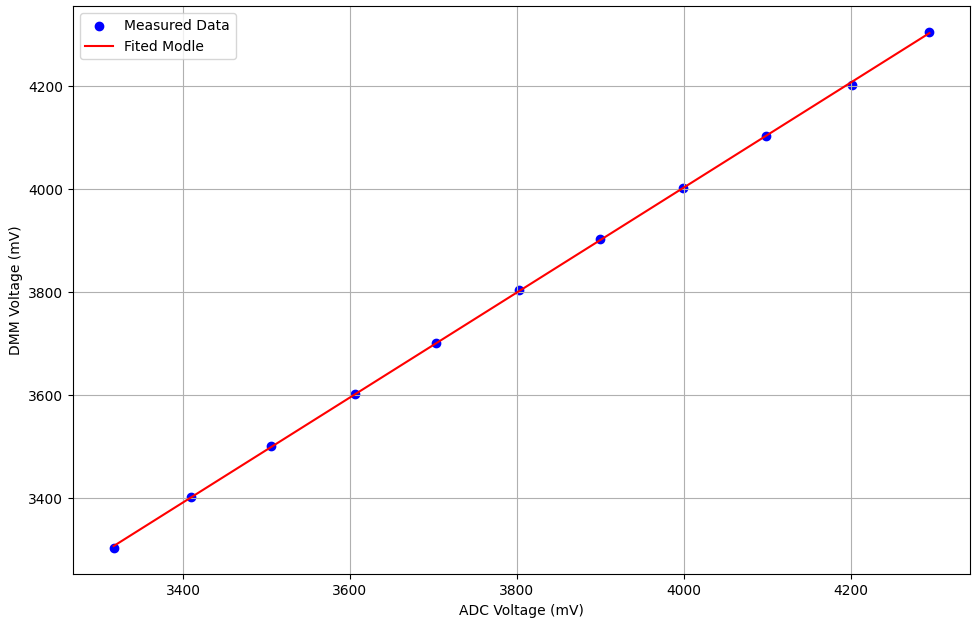
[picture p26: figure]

Figure 11: Calibration Plot Showing Device vs. Reference voltage with Linear Fit

Best-fit parameters:

- Slope (a): 1.0188
- Offset (b): –72.6815 mV
- Coefficient of determination (R²): 0.999917

Residual statistics

- Mean residual: ≈ 4.5×10^(-13) mV → effectively 0 mV
- Standard deviation: 2.89 mV
- Maximum absolute residual: 6.3 mV (at 4201 mV point)

Note: -

After calibration, the ADC readings follow the model with max error ≈ ±6.3 mV, but the absolute accuracy is limited by the DMM’s ±25 mV.

Fitted model with uncertainty:

V_(Calibrated) (mV)=1.0188 ×V_(ADC) (mV)-72.6815 ±25 mV

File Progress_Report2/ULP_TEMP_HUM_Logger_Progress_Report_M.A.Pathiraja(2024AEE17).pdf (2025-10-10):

## Development of an Ultralow-Power Battery-Operated Temperature and Humidity Data Logger

M.A. Pathiraja (2024AE17)

## Current Progress

I have developed a compact, ultra-low-power environmental data logger consuming less than 25 µA in deep-sleep mode. It reliably records timestamped temperature and humidity data and can be easily configured, downloaded, and analyzed using a PC tool.

### Objectives & Progress

- Logn lasting operation on single battery charge (More than one month) – 100% (Projected more than one year)
- Accurate temperature & humidity logging with timestamps. – 100%
- RTC fail safe mechanism - 100%
- Retrieve data from device to PC – 100%
- Change device configuration without re-flashing the firmware. – 100%
- Outdoor‑ready waterproof design. – 100%

### 1. Major Achievements

- Low-Power Optimized Prototype – Fully functional hardware designed for ultra-low energy consumption.
- Measured Deep-Sleep Current: ~20.48 µA (verified using Nordic PPK2)
- ULP-Optimized Firmware – Includes deep-sleep mode, RTC-based wake-up, CSV data logging.
- Data Retrieval & Config mode – Download stored data and config device settings via UART configuration interface.
- PC GUI Tool – Supports device configuration, data download and formatting, data visualization and analysis


Figure 1: Current Prototype Without Enclosure


Figure 2: Assembled Prototype in Enclosure


Figure 3: Magnetically attachable data cable


Figure 4: Prototype Front Panel view (Indicator LED’s ON)

### 2. Hardware Overview

### 2.1 Current Hardware Specifications

- MCU: ESP32-H2 (RISC-V) with integrated BLE
- Sensor: SHT45 (Temperature and Humidity)
- RTC: PCF8523 (Version 1)
- Storage: LittleFS (https://docs.espressif.com/projects/esp-idf/en/stable/esp32/api-guides/file-system-considerations.html) file system on internal flash memory SPIFFS partition.
- Power Supply: 3.7 V Li-Po battery with built-in charging and protection circuit
- I/O Interface: Magnetic pogo-pin connector
- Enclosure: IP65-rated waterproof housing


### 2.2 Planned Hardware Improvements (Already Implemented in final prototype PCB)

- Precision ULP ADC for battery measurement (improves SoC accuracy).
- RV3028 temperature‑compensated RTC (±1 ppm).
- External SPI flash (16 Mbit) for extended logging capacity.
- Dedicated power‑path controller for seamless USB/battery switching.
- Commercial grade PCB design.

Figure 5: Datalogger PCB design Layout (with improved hardware features)

Figure 6: Datalogger PCB design 3D view


Figure 7: USB adapter PCB design Layout


Figure 8: USB adapter PCB design 3D view

### 3. Firmware Status & Roadmap

### 3.1 Current Firmware specifications

- Deep Sleep Operation – Minimizes power consumption during idle periods.
- CSV Logging – Stores timestamped data records in CSV format and create new csv file for each day.
- RTC Fail safe Operation – If RTC failed calculate the time from last record.
- UART Configuration – Allows device setup and parameter adjustment via serial interface.
- Data Retrieval – Easily view stored records and download to PC.
- Persistent Settings – Retains user configurations across power cycles.
- LED Control – Provides visual status indication through programmable LED behavior.

### 3.2 Planned Firmware Improvements

- BLE Data and Configuration – Enables wireless data transfer and device setup via Bluetooth Low Energy.
- External Flash Storage– Supports continuous data logging combining external flash memory.
- Battery Runtime Estimation and Adaptive Sampling – Adjusts sampling rate for estimating battery capacity.

### 4. PC GUI Tool

A PC-based GUI tool was developed for easy configuration and analysis of the data logger. It enables users to adjust settings, synchronize the RTC, view live data, and download or manage stored logs. The interface features automatic COM detection and real-time plotting for quick and intuitive operation.


Figure 9: Connection/Configuration UI


Figure 10: Data Management UI


Figure 11: Visualization (Temp/RH/VBAT)

Those are the implemented GUI Features,

- Automatic COM Port Detection – Identifies connected devices instantly.
- Live Status Monitoring – Displays real-time device activity and connection state.
- Firmware, Battery, and Storage Information – Shows system version, battery level, and memory usage.
- Set Logging Interval – Adjust data recording frequency as needed.
- RTC Synchronization – Sync device time with PC for accurate timestamps.
- LED Control – Enable or disable status LED indication.
- Save Configuration Parameters – Store user-defined settings permanently.
- List and Download Logs – Browse and retrieve recorded data files.
- Format Storage – Clear or reinitialize internal memory.
- Real-Time Plotting – Visualize live sensor data on PC.

### 5. Power Consumption


Measurement tool: Nordic PPK2 (https://www.nordicsemi.com/Products/Development-hardware/Power-Profiler-Kit-2) (source mode , Voltage = 3.7 V).

- Deep‑sleep: ~20.48 µA (max ~22.28 µA).
- Active logging (1 s every 5 min): average ~8.05 mA across the cycle.

Projected battery life (2000 mAh , 10‑min interval): ≈ 1.4 years (theoretical).

Figure 12: Deep‑Sleep Current Profile

Figure 13: Active Logging Profile

### 6. Data Storage & Runtime

- Average record size: ≈ 24 bytes
- One-day CSV (10 min sampling): ≈ 3.5 KB
- LittleFS capacity: ≈ 1.38 MB
- Estimated retention: ≈ 395 days (with 5 % safety margin)
- Maximum possible: ≈ 415 days continuous logging before full

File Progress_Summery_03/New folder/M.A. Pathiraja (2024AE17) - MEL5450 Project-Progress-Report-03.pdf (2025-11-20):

## Development of an Ultralow-Power Battery-Operated Temperature and Humidity Data Logger

M.A. Pathiraja (2024AE17)

## Current Progress

I have developed a compact, ultra-low-power environmental data logger that consumes less than 25 µA in deep-sleep mode. The device reliably records timestamped, calibrated temperature and humidity measurements and supports easy configuration, data download, and analysis through a dedicated PC software tool.

### Objectives & Progress

- Long lasting operation on single battery charge (More than one month) – 100% (Projected more than one year)
- Accurate temperature & humidity logging with timestamps. – 100%
- Sensor readings were calibrated – 100%
- Retrieve data from device to PC – 100%
- Change device configuration without re-flashing the firmware. – 100%
- Outdoor‑ready waterproof design. – 100%

### 1. Major Achievements

- Low-Power Optimized Prototype – Fully functional hardware designed for ultra-low energy consumption.
- Calibrated Sensors – Temperature and Humidity readings were calibrated.
- Ultra-low power Consumption: Measured sleep current (22.28 µA) (verified using Nordic PPK2)
- ULP-Optimized Firmware – Includes deep-sleep mode, RTC-based wake-up, encoded data logging.
- Data Retrieval & Config mode – Download stored data and config device settings via UART configuration interface.
- PC GUI Tool – Supports device configuration, data download and formatting, data visualization and analysis
- Rugged Design - IP65 rated Outdoor‑ready waterproof design.

### 2. Device Overview


Figure 1: ULP Datalogger TOP view with Magnetic USB adapter


Figure 2: ULP Datalogger Front Panel

### 3. Hardware Overview

- MCU: ESP32-H2 (RISC-V) with integrated BLE
- Sensor: SHT45 Temperature and Humidity Sensor. (calibrated)
- RTC: RV3028 temperature‑compensated RTC (±1 ppm).
- Storage: Internal flash (11Mbit) and (16Mbit) external flash.
- Power Supply: 3.7 V Li-Po battery with built-in charging and protection circuit
- I/O Interface: Magnetic pogo-pin connector
- Precision ULP ADC: For accurate battery voltage measurement (Calibrated).
- Enclosure: IP65-rated waterproof housing


Figure 3: Datalogger PCB assembled


Figure 4: USB adapter PCB Assembled

### 4. Firmware specifications

- Deep Sleep Operation – Minimizes power consumption during idle periods.
- Data Logging – Stores timestamped data records in (7-byte) binary format.
- UART Configuration – Allows device setup and parameter adjustment via serial interface.
- Data Retrieval – Easily view stored records and download to PC.
- Persistent Settings – Retains user configurations across power cycles.
- LED Control – Provides visual status indication through programmable LED behavior.

### 5. PC GUI Tool

A PC-based GUI tool was developed for easy configuration and analysis of the data logger. It enables users to adjust settings, synchronize the RTC, view live data, and download or manage stored logs. The interface features automatic COM detection and real-time plotting for quick and intuitive operation.

Implemented GUI Features,

- Firmware, Battery, and Storage Information – Shows system version, battery level, and memory usage.
- Set Logging Interval – Adjust data recording frequency as needed.
- RTC Synchronization – Sync device time with PC for accurate timestamps.
- Save Configuration Parameters – Store user-defined settings permanently.
- List and Download Logs – Browse and retrieve recorded data files.
- Format Storage – Clear or reinitialize internal memory.
- Real-Time Plotting – Visualize live sensor data on PC.


Figure 5: Connection/Configuration UI

Figure 6: Visualization (Temp/RH/VBAT)

### 6. Power Consumption


Measurement tool: Nordic PPK2 (https://www.nordicsemi.com/Products/Development-hardware/Power-Profiler-Kit-2) (source mode , Voltage = 3.7 V).

- Deep‑sleep: ~20.48 µA (max ~22.28 µA).
- Active logging (1 s every 5 min): average ~8.05 mA across the cycle.

Projected battery life (2000 mAh , 5‑min interval): ≈ 1 years (theoretical).

Figure 7: Deep‑Sleep Current Profile (Avg sleep current around 20.48 uA)

Figure 8: Active Logging Profile (Avg active current around 8.05 mA)

### 7. Data Storage & Runtime

- Single record size: ≈ 7 bytes
- One-day (5 min sampling): ≈ 2 KB
- Total Storage capacity: ≈ (1.38 MB + 2MB) = 3.38 MB
- Estimated retention: ≈ 1600 days (with 5 % safety margin)
- Maximum possible: ≈ 360 days continuous logging. (From Single battery Charge)

### 8. Temperature & Humidity Sensor Calibration

The temperature calibration of the SHT45 sensor was performed at an ISO/IEC 17025 accredited laboratory (IMC, Sri Lanka). Five calibration points were evaluated across the operating range of the sensor. The reference thermometer uncertainty is incorporated into the expanded uncertainty reported by the lab.

- Device Under Test (DUT): Temperature and Humidity Logger (SHT45 Sensos)
- Reference Instrument: Digital thermometer with Pt1000 sensor (Reg No:(7424)362-0191A)
- Measurement Range: Temperature :10°C to 50°C , Humidity: 55.00 %RH and 72.00 %RH

Measurement Data (Provided by Laboratory):

i)Temperature Measurement

Table 8.1: Reference Temperature and Device (Sensor) readings with correction and expanded
uncertainty (K=2 , for 95% confidence level)
Reference Temperature (°C) | Device Reading (°C) | Correction (°C) | Expanded Uncertainty, U (°C)
9.79 | 10.33 | −0.54 | ±0.20
19.60 | 20.06 | −0.46 | ±0.20
29.67 | 29.91 | −0.24 | ±0.20
39.90 | 40.35 | −0.45 | ±0.20
49.89 | 50.28 | −0.39 | ±0.20

ii) Relative Humidity Measurement

Table 8.2: Reference Humidity and Device (Sensor) readings with correction and expanded uncertainty (K=2, for 95% confidence level)

Reference Humidity (%) | Device Reading (%) | Correction (%) | Expanded Uncertainty, U (%)
55.00 | 53.21 | 1.79 | ±3
72.00 | 73.15 | -1.15 | ±3

### i) Temperature calibration

A linear regression was performed to relate Device temperature reading to true reference temperature,

Performed linear regression to model:

TCorrected = m × Tdevice + b | (01)


Figure 9: Calibration Plot Showing Device vs. Reference Temperature with Linear Fit

Best-fit parameters:

- Slope (a): 1.00302
- Offset (b): -0.5073 °C
- Coefficient of determination (R²): 0.9999

Residual statistics

- Mean residual: 0 °C
- Standard deviation: 0.101167 °C
- Maximum absolute residual: 0.176835 °C

Uncertainty Calculation

The lab guarantees the reference temperature is correct within ±0.20 °C with 95% confidence. [multiplying the combined standard uncertainty by a coverage factor k = 2]

Therefore, Lab Reference standard uncertainty = 0.10°C

Calibration model Uncertainty (S.D of residuals) = 0.101167 °C

The Lab reference uncertainty and model fitting uncertainty are independent.

Combine them using root-sum-of-squares (RSS):

uc = √ulab
2 | + umodle
| 2

Where, ulab = 0.1°C , umodle = 0.101167 °C

Substitute values:
uc = 0.1414 °C

Therefore, uncertainty expanded (k=2 for 95% confidence) U = 2 × 0.1414 °C = 0.2828°C

Fitted model with uncertainty:

TCorrected(°C) = (1. 00302 × Tdevice (°C) − 0. 5073 ) ± 0. 28°C

(02)

(03)

### ii) Relative Humidity calibration

The accredited laboratory provided only two calibration points,

Since only two points were provided, a 2-point linear calibration was derived as ,

RHCorrected = m × RHdevice + b

The slope m and intercept b were calculated directly using,

m =

R2−R1
D2 − D1

= 0.8525

b = R1 − m × D1 = 9.6354


Figure 10: Two-Point Humidity Calibration Curve Showing Device Readings vs. Reference Relative Humidity with Fitted Linear Model

(04)

(05)

(06)

Uncertainty Calculation

The lab guarantees the reference relative humidity is correct within ±3 %RH with 95% confidence. [multiplying the combined standard uncertainty by a coverage factor k = 2]

Therefore, Lab Reference standard uncertainty = 1.5 % RH

The fitted model itself contributes no statistically estimable additional uncertainty (u_fit ≈ 0 %RH, artefact of 2-point line).

Therefore , Calibration model Uncertainty (S.D of residuals) = 0 % RH

The Lab reference uncertainty and model fitting uncertainty are independent.

Combine them using root-sum-of-squares (RSS):

uc = √ulab
2 | + umodle
| 2

Where, ulab = 1.5 % RH , umodle = 0 % RH

Substitute values:
uc = 1.5 % RH

Therefore, uncertainty expanded (k=2 for 95% confidence) U = 2 × 1.5 % RH = 3 % RH

Fitted model with uncertainty:

RHCorrected(%RH) = (0. 8525 × RHdevice (%RH) + 9. 6354) ± 3% RH

(07)

(08)

### 9. ADC Calibration (Battery Voltage measurement)

The MCP3021 (12-bit) ADC was used to measure the battery voltage in the custom ESP32-H2 data logger hardware.

- Device Under Test (DUT): Custom PCB with ESP32-H2 and MCP3021 ADC
- Reference Instrument: Digital Multimeter (DMM, ±25mV at range (9.999V))
- Voltage Source: Bench DC power supply
- Measurement Range: 3300–4300 mV

Measurement Data:

Multiple voltages measured (Supplied from Bench power supply in range 3.3V to 4.3V) simultaneously by the DMM and ADC (uncalibrated firmware output).

Table 9.2: Reference Voltage and ADC computed Voltage in mV
Reference Voltage (mV) [±25 mV] | ADC Measurement (mV)
3302 | 3317
3401 | 3409
3501 | 3506
3601 | 3606
3701 | 3703
3804 | 3802
3903 | 3899
4001 | 3999
4102 | 4098
4201 | 4201
4304 | 4294

Linear Regression Model

A linear model was fitted to relate the ADC reading (input) to the true reference voltage,

VCalibrated = a × VADC + b


Figure 11: Calibration Plot Showing Device vs. Reference voltage with Linear Fit

Best-fit parameters:

- Slope (a): 1.0188
- Offset (b): –72.6815 mV
- Coefficient of determination (R²): 0.999917

Residual statistics

- Mean residual: ≈ 4.5 × 10⁻¹³mV → effectively 0 mV
- Standard deviation: 2.89 mV
- Maximum absolute residual: 6.3 mV (at 4201 mV point)

Note: -

After calibration, the ADC readings follow the model with max error ≈ ±6.3 mV, but the absolute accuracy is limited by the DMM’s ±25 mV.

Fitted model with uncertainty:

VCalibrated (mV) = 1. 0188 × VADC(mV) − 72. 6815 ± 25 mV

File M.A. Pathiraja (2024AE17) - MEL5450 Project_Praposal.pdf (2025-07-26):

MEL 5450: Embedded Systems Project

1

## Development of an ultralow-power battery-operated data logger

M.A. Pathiraja (2024AE17)
2025.07.26

### 1. Introduction

Accurate environmental monitoring underpins climate science, ecological investigation, and agricultural optimization; however, extant data‐logging instruments are often prohibitively expensive, necessitate frequent battery replacement, and exhibit limited resilience in adverse outdoor settings. This proposal outlines the Development of an Ultralow-Power, Battery-Operated Data Logger for sustained field deployment. The architecture integrates an energy-efficient microcontroller, a factory-calibrated temperature and humidity sensors, and firmware optimized through deep-sleep operation, clock scaling, and adaptive duty cycling to minimize energy consumption. A smart power-budget algorithm, in concert with either rechargeable (Li-ion) or primary cell chemistries and ultra-low-leakage voltage regulation, facilitates autonomous operation exceeding one month on a single charge. Recorded data are preserved in onboard nonvolatile memory with precise timestamps, while the IP65-rated enclosure with sealed connectors and corrosion-resistant push button to ensure mechanical robustness. Collectively, these design choices yield a maintenance-free, rugged solution for long-term environmental data acquisition in challenging field environments.

2. Targets

The main targets to be achieved to complete the project are,

- Accurately measure and record ambient temperature.
- Measure and record relative humidity.
- Operate autonomously for at least one month on a single battery charge.
- Buffer and organize time-stamped data in non-volatile local storage.
- Monitor battery voltage and gracefully shut down before depletion.
- Withstand outdoor conditions with a waterproof, rugged enclosure.

MEL 5450: Embedded Systems Project


2

3. Methodology

The ultralow-power data logger is predicated on a microcontroller that remains in deep-sleep until awakened by an RTC alarm or timer-interrupt, at which point it acquires temperature and humidity measurements from a factory-calibrated sensor (e.g., AHT2415C) and assesses the battery voltage. Upon wakeup, the device records these time-stamped readings to nonvolatile memory before promptly returning to its low-power state. Quiescent current is minimized using an ultra-low-leakage LDO, while optimized firmware algorithms further reduce active-mode energy consumption. A GPIO-controlled resistor divider, which engages only during voltage measurement to eliminate idle current draw, scales the battery pack voltage for ADC conversion and dynamically adjusts the data-collection interval to extend operational longevity. The push button, status LED and USART interface will be used to allow users to interact with the firmware to change certain settings. The Power is replenished via a waterproof charging interface that accommodates a Li-ion charger and batterymanagement system (BMS), ensuring cell protection. Collectively, these design features facilitate over more than one month of autonomous, maintenance-free outdoor operation on a single battery charge.

Figure 3.1: Block Diagram of the System

Figure 3.2: Block Diagram of the power supply

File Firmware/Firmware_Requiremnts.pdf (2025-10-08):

### Requirement

Low power data logging

Read RTC , TEMP sensor and aquire data

Store data on to flash memory as a CSV files using LIttleFs File System

Flash Waear Leaveing

Indicator LED Functions -> Wakeup Indicate , Config Mode

Battery Voltage analo Reading

Download Mode , whan button press at boot

View Logged data from Flash memeory. (Show information Size,Raw Count)

Delete a file and folder from the storage.

Download Logged data from Flash memeory to Computer via USB.

Set Device parameters

Set RTC Date
Set RTC Time
Sync RTC Date Time From PC Set data log interval
Set heartbeat STATUS LED

View Device Parameters

View RTC Date
View RTC Time
View data log interval
View Battery Voltage
View Sensor Readings
View Avilble Storage
View heartbeat STATUS LED configs

Restart Logger via USb Serial commands.

Format Storage. (Password Protected)

Download all the data files once.

RTC Fail Safe Logging meachnism.

External Flash storage usage if internal got full. Also data retrival from extranl flash storage

UART based data transfer and config

Blutoothe based wirles config and data transfer

Python based GUI Config data , analyze data on PC

Status LED Heartbeat Feature

Data Analyz tool

Temp,Hume,Vabt vs Time
Reduce data points interval (Down Sample) Zoom to specific time interval
plot moving avg cureve (N-Point)
Find Min,MAX,AVG
Remove outliars

Developed | Tested
Yes | Yes
Yes | Yes
Yes | Yes
Yes | Yes
Yes | Yes
Yes | Yes
Yes | Yes
Yes | Yes
Yes | Yes
Yes | Yes
Yes | Yes
Yes | Yes
Yes | Yes
Yes | Yes
Yes | Yes
Yes | Yes
Yes | Yes
Yes | Yes
Yes | Yes
Yes | Yes
Yes | Yes
Yes | Yes
Yes | Yes
Yes | Yes

No | No
Yes | Yes
No | No
Yes | Yes
No | No
Partially | Partially
Yes | Yes

### Comments

Sleep Mode Currrent : 25 uA Active mode avg Current : 8.05mA

Automatiaclly handle by littleFs File System.

Tested and calibrated in range (3.3V to 4.3V)

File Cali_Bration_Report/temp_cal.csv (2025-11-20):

Reference | Device
9.79 | 10.33
19.6 | 20.06
29.67 | 29.91
39.9 | 40.35
49.89 | 50.28

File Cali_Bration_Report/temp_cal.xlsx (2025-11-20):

Reference Temperature (°C) | Device Reading (°C) | Correction (°C) | Expanded Uncertainty, U (°C)
9.79 | 10.33 | −0.54 | ±0.20
19.6 | 20.06 | −0.46 | ±0.20
29.67 | 29.91 | −0.24 | ±0.20
39.9 | 40.35 | −0.45 | ±0.20
49.89 | 50.28 | −0.39 | ±0.20

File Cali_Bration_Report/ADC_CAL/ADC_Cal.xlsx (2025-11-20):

DMM | ADC | After_Calibration
3.3 | 3.3167 | 3307
3.401 | 3.4086 | 3405
3.501 | 3.5059 | 3506
3.601 | 3.6055 | 3604
3.701 | 3.7028 | 3706
3.8 | 3.8024 | 3804
3.9 | 3.8997 | 3907
4 | 3.9993 | 4009
4.1 | 4.0977 | 4107
4.2 | 4.2006 | 4206
4.3 | 4.2935 | 4307
CAL_SLOPE = 1.0164083f
CAL_OFFSET_V = -0.0650094

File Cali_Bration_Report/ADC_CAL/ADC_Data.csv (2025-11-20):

DMM Reading (V) | Battery_Voltage (Uncalibrated) (V)
3.3 | 3.3167
3.401 | 3.4086
3.501 | 3.5059
3.601 | 3.6055
3.701 | 3.7028
3.8 | 3.8024
3.9 | 3.8997
4 | 3.9993
4.1 | 4.0977
4.2 | 4.2006
4.3 | 4.2935

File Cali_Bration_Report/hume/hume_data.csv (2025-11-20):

Reference | Device
55 | 53.21
72 | 73.15

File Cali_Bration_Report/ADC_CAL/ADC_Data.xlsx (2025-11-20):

DMM Reading (mV) [+- 1 mV] | ADC_Measurment (mV) [+-3mV]
3302 | 3317
3401 | 3409
3501 | 3506
3601 | 3606
3701 | 3703
3804 | 3802
3903 | 3899
4001 | 3999
4102 | 4098
4201 | 4201
4304 | 4294

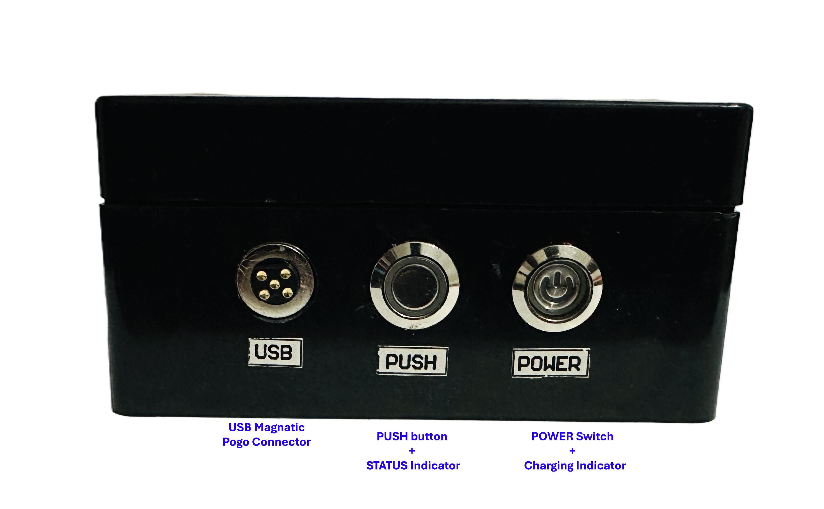
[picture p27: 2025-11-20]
Hardware_Design/Images/Prototype/New folder/Designer (1).png

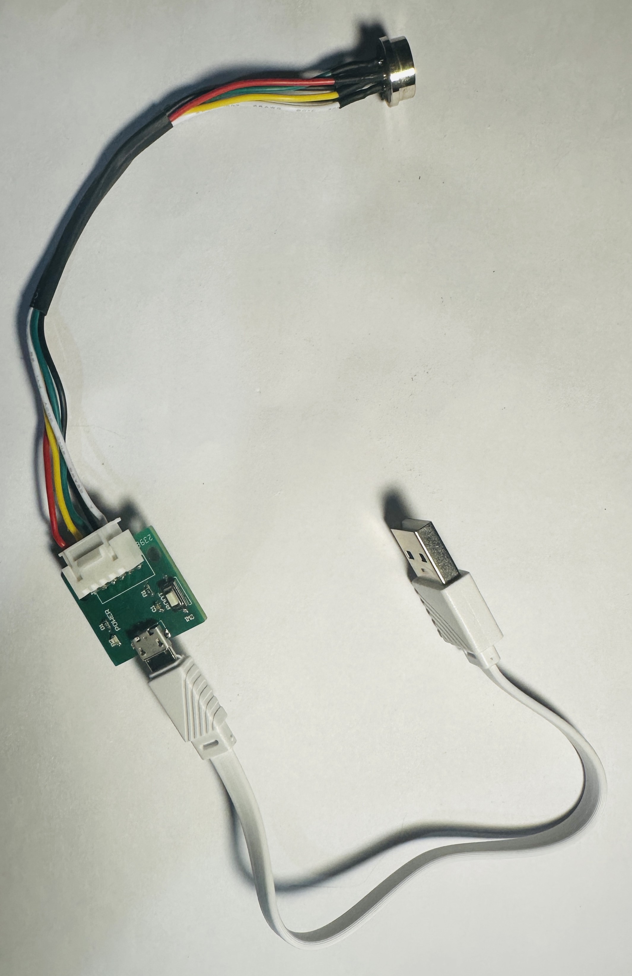
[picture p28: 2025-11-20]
Hardware_Design/Images/Prototype/New folder/Harness.jpg

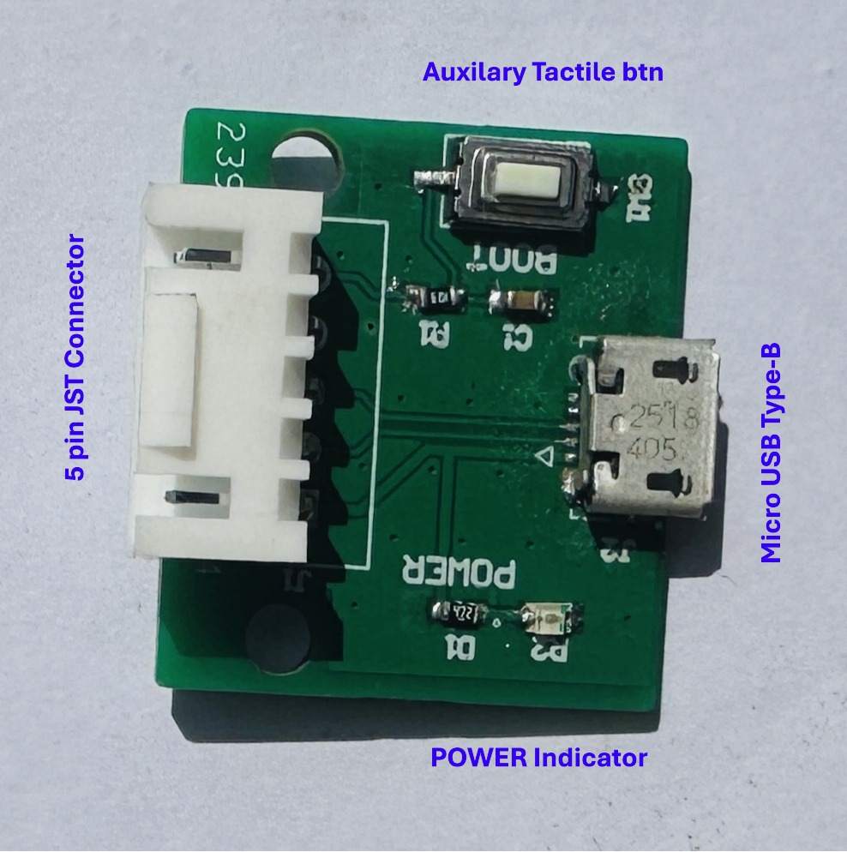
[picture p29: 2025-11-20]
Hardware_Design/Images/Prototype/New folder/Adapter_PCB.JPG

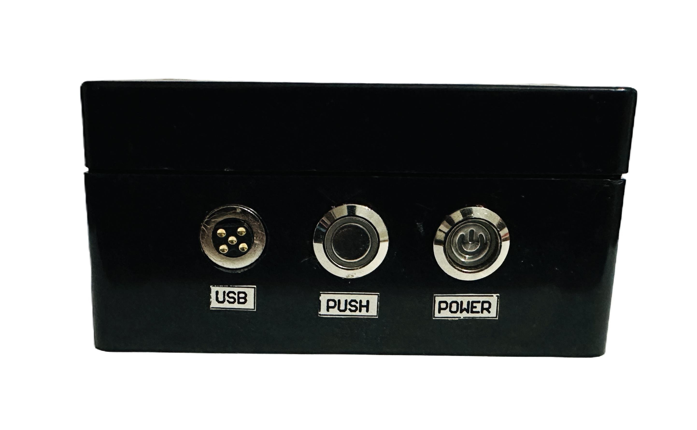
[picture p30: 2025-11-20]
Hardware_Design/Images/Prototype/New folder/New_Prtotype_FP.JPG

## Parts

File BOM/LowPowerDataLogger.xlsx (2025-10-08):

Comment | Designator | Footprint | Quantity | LCSC
ESP32-H2-MINI-1-N4 | B1 | ESP32-H2-MINI-1-N4 | 1 | C18203134 | AliExpress: | https://www.aliexpress.com/item/1005005507604229.html?sourceType=1
MCP3021 | B2 | MCP3021A5T-E_OT | 1 | C128576 | Select Option : | ESP32-H2-MINI-1-N4
W25Q64JVSSIQ | B3 | W25Q64JVSSIQ | 1 | C179171
AP2331W-7 | B4 | AP2331W-7-(SOT-23-3) | 1 | C500764
DW03 | B5 | DW03 | 1 | C18198382
MCP1700T | B7 | MCP1700T-SOT23 | 1 | C39051
100 nF | C1, C4, C6, C8, C9, C10, C11, C14, C15, C17, C19, C23, C30 | CAP_0603 | 13 | C1591
22 uF | C2 | CAP_0603 | 1 | C86295
10 nF | C3, C13 | CAP_0603 | 2 | C1589
1 uF | C5, C7, C12, C16, C18, C26, C27, C31 | CAP_0603 | 8 | C95843
10 uF | C20, C21, C22, C29 | CAP_0603 | 4 | C19702
47 uF | C24 | CAP SMD 1206 | 1 | C96123
100 uF | C25 | CAP SMD 1206 | 1 | C883598
2.2 uF | C28 | CAP_0603 | 1 | C23630
BSD3A031V | D1 | MCC_SOD-323_IPC_A | 1 | C151999
USBLC6-2SC6 | D2 | USBLC6-2SC6 | 1 | C7519
RED | D4 | LED SMD 0603 | 1 | C965799
YELLOW | D5 | LED SMD 0603 | 1 | C965802
PESD5V0S1BA | D6, D7 | TVS_SOD-323 | 2 | C19224
LM66100DCKR | D8, D9 | LM66100DCKR | 2 | C2869734
MF-MSMF050-2 | F1 | Fuse_SMD_1812_1A | 1 | C17313
BLM18KG601SN1D | FB1, FB2 | FBead_Murata_BLM18KG601SN1D | 2 | C85833
JST_4P_P=2.5mm | J1, J2, J3, J5 | JST_4P_Straight_P=2.5mm | 4 | C7429634
Bat_Con_CR1220 | J4 | Bat_Con_CR1220 | 1 | C969906
2_Way_JST | J6 | 2_Way_JST_Connector | 1 | C158012
1051330011 | J9 | USB_Micro_B_90_MOLEX_1051330011 | 1 | C586226
UMH3NTN-(Dual Transistor With Base Res) | Q1 | UMH3NTN-(Dual Transistor With Base Res-SOT-363) | 1 | C123008
MMBT2222* | Q2 | Bipolar _BJT_ Transistor | 1 | C82460
10 KOhm | R1, R2, R4, R12, R15, R16, R25, R32, R33 | Res_0603 | 9 | C2930027
3.3 KOhm | R6 | Res_0603 | 1 | C22978
33 Kohm , (0.1%) | R7, R10 | Res_0603 | 2 | C705768
1 KOhm | R8,R13, R24, R29, R30 | Res_0603 | 5 | C22548
100 Kohm , (0.1%) | R9, R14, R17, R18, R19, R21 | Res_0603 | 6 | C122538
4.7 KOhm | R11 | Res_0603 | 1 | C99782
470 KOhm | R22 | Res_0603 | 1 | C114622
22KOhm | R23 | Res_0603 | 1 | C114065
470 Ohm | R26 | Res_0603 | 1 | C23179
0.2 Ohm , 1W | R27 | RES_2512 | 1 | C83749
1.33 KOhm , 1% | R28 | Res_0603 | 1 | C861196
100 Ohm | R31, R34, R36 | Res_0603 | 3 | C105588
1.5 MOhm | R35 | Res_0603 | 1 | C4172
560 Ohm | R37 | Res_0603 | 1 | C114629
SPST_SMD_Tactile_sw | SW1, SW2, SW3 | SPST_SMD_6mm | 3 | C318938
CH343K | U1 | CH343K | 1 | C5832295
SI2333CDS | U2, U6 | SOT-23 | 2 | C48179
SI2302CDS | U3, U7 | SOT-23 | 2 | C10488
RV-3028-C7 | U4 | IC_RV-3028-C7 | 1 | C3304278
TP4056 | U5 | TP4056-SOP-8-EP | 1 | C7473158
4P JST Male (P=2.5mm) | Select Option :- | Pitch = 2.5mm , 4 Pin , Male , Length =10cm |  | https://vi.aliexpress.com/item/1005001649158434.html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

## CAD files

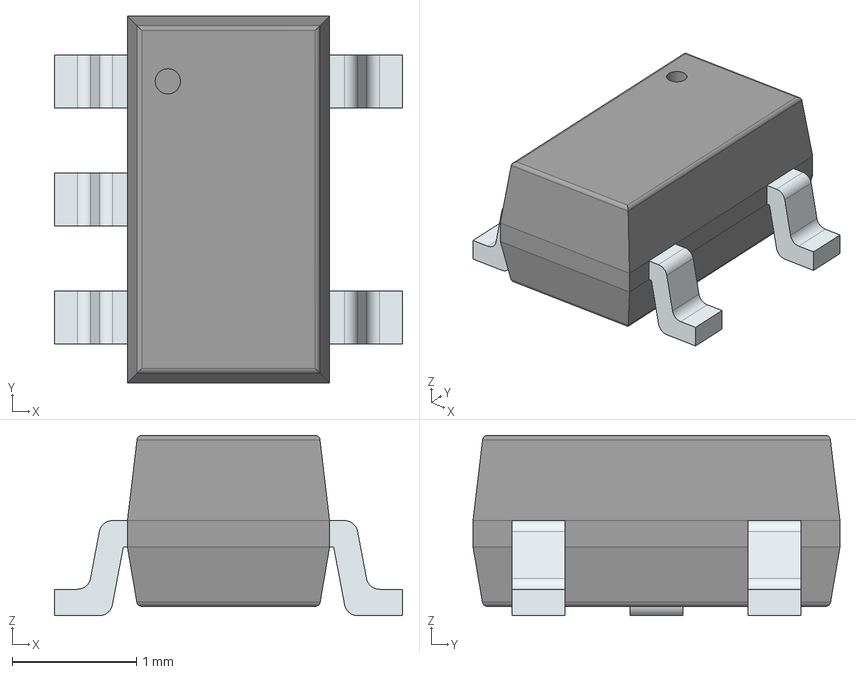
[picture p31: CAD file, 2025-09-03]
DataSheet/ADC/LIB_MCP3021A5T-E_OT/MCP3021A5T-E_OT/3D/MCP3021A5T-E_OT.stp
2.80 x 2.95 x 1.45 mm
PinsArrayL
PinsArrayR

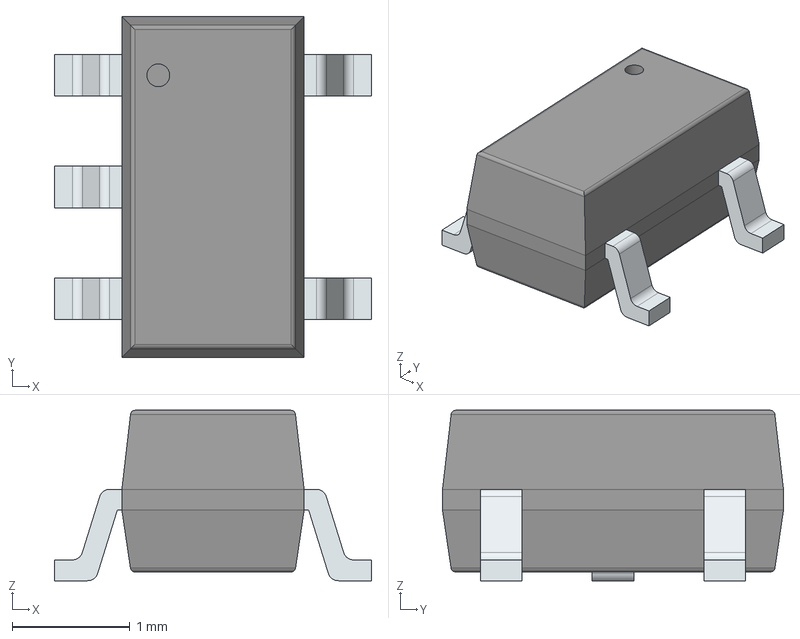
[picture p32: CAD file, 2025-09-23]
DataSheet/BATTERY_Protection/LIB_24AA02E48T-I_OT/24AA02E48T-I_OT/3D/DW03.stp
2.70 x 2.90 x 1.45 mm
PinsArrayL
PinsArrayR

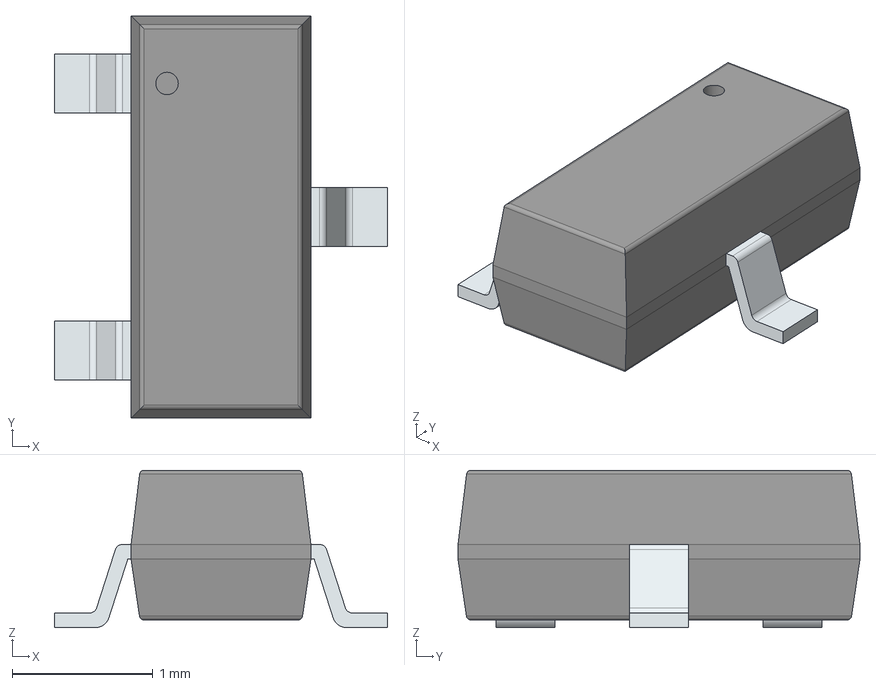
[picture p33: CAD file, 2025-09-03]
DataSheet/LDO/LIB_MCP1700T-3302E_TT/MCP1700T-3302E_TT/3D/MCP1700T-SOT23.stp
2.37 x 2.86 x 1.12 mm
PinsArrayL
FilletPinR

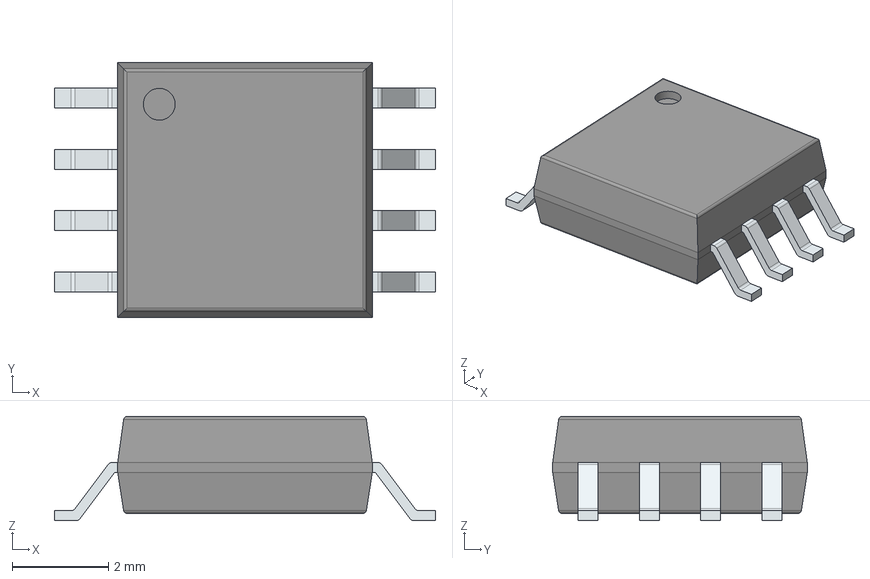
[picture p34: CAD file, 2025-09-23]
DataSheet/NOR_Flash/LIB_W25Q64JVSSIQ/W25Q64JVSSIQ/3D/W25Q64JVSSIQ.stp
7.90 x 5.28 x 2.16 mm
PinsArrayLR

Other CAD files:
DataSheet/ADC/LIB_MCP3021A5T-E_OT/MCP3021A5T-E_OT/Allegro/sot95p280x145-5n.psm
DataSheet/ADC/LIB_MCP3021A5T-E_OT/MCP3021A5T-E_OT/DEHDL/mcp3021a5t_e_ot/chips/chips.prt
DataSheet/BATTERY_Protection/LIB_24AA02E48T-I_OT/24AA02E48T-I_OT/Allegro/sot95p270x145-5n.psm
DataSheet/BATTERY_Protection/LIB_24AA02E48T-I_OT/24AA02E48T-I_OT/DEHDL/24aa02e48t_i_ot/chips/chips.prt
DataSheet/LDO/LIB_MCP1700T-3302E_TT/MCP1700T-3302E_TT/Allegro/sot95p237x112-3n.psm
DataSheet/LDO/LIB_MCP1700T-3302E_TT/MCP1700T-3302E_TT/DEHDL/mcp1700t_3302e_tt/chips/chips.prt
DataSheet/NOR_Flash/LIB_W25Q64JVSSIQ/W25Q64JVSSIQ/Allegro/soic127p790x216-8n.psm
DataSheet/NOR_Flash/LIB_W25Q64JVSSIQ/W25Q64JVSSIQ/DEHDL/w25q64jvssiq/chips/chips.prt

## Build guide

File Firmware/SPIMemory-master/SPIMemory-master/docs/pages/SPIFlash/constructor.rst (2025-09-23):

.. _Constructor:

.. cpp:class:: SPIFlash
.. cpp:function:: SPIFlash::SPIFlash(uint8_t cs = CS, SPIClass *spiinterface = &SPI)

.. default-domain:: cpp
.. highlight:: cpp
  :linenothreshold: 4

##########################
Constructor ``Mandatory``
##########################

.. note::

  A constructor is a special kind of class member function that is executed when an object of that class is instantiated.
  Constructors are typically used to initialize member variables/functions of the class to appropriate default values, or to allow the user to easily initialize those member
  variables/functions to whatever values are desired. [*]_

************************
Parameters ``Optional``
************************
.. cpp:var:: uint8_t cs

    Refer to :ref:`Defining a custom Chip Select pin <customCSPin>`

.. cpp:var:: SPIClass *spiinterface

    Refer to :ref:`Using a non-default SPI interface <nonDefaultSPI>`

********************
What it does
********************

Returns ``Nothing``
---------------------

* The constructor must be called before ``void setup()``. The constructor can be any word of your choice. For example, the library can called by the example code below where ``flash`` can be replaced by a constructor of the user's choice.

* The constructor is used to call a function from the SPIFlash library.

********************
Example code:
********************

.. code-block:: cpp

  #include <SPIMemory.h>

  SPIFlash flash;   //This is the constructor. This example uses 'flash' as the constructor

    void setup() {
    ...
    }

    void loop() {
    flash.readByte(...);  //The constructor 'flash' is used to call the function 'readByte()' from the library
    ...
    }

************************
Related Errors ``None``
************************

.. _advancedUseConstructor:

********************
Advanced Use
********************

.. _customCSPin:

Defining a custom Chip Select pin
------------------------------------
The library can also called by declaring the ``cs`` parameter in the constructor where ``cs`` is the uuser defined Chip Select pin for the flash module.

.. code-block:: cpp

  #include <SPIMemory.h>

  SPIFlash flash(33);   // The library uses the `pin 33` as the Chip Select pin instead of the default

  void setup() {
    ...
  }

  void loop {
    ...
  }

-------------------------------------

.. _nonDefaultSPI:

Using a non-default SPI interface [*]_
----------------------------------------

* The library currently only supports using non-default SPI interfaces on the following architectures:
    * SAMD
    * STM32
* The csPin **MUST** be declared if using a non-default SPI interface.
* Only available if library > v3.0.0

.. code-block:: cpp

  #include <SPIMemory.h>

  SPIFlash flash(33, &SPI1);  // The library now uses the 'SPI1' interface instead of the default 'SPI0'.
                              // It also uses pin 33 instead of the default Chip Select pin
  void setup() {
    ...
  }

  void loop {
    ...
  }

.. rubric:: Footnotes
.. [*] `learncpp.com <http://www.learncpp.com/cpp-tutorial/85-constructors/>`_.
.. [*] This is currently only supported on the SAMD and STM32 architectures.

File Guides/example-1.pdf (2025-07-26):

MEL 5450:Embedded Systems Project

# Computer Controlled Variable Power Supply

Vahesan Jeyarajalingam (2015bAE15)

04/07/2017

## 1. Introduction

A computer controlled variable power supply is a DC power supply in which the output voltage can be adjusted using a computer interface. The objective of this project is to build a fully digital control power supply with a user interface with features like voltage sweep.

An AC - DC power supply steps down the AC voltage and converts it to a fixed DC voltage which will be then varied.

MOSFET stands for metal-oxide semiconductor field-effect transistor. It is a special type of field-effect transistor (FET). A MOSFET is used for varying the output voltage. MOSFET is a voltage controlled device. MOSFETs have “gate“, “Drain” and “Source” terminals. MOSFET may be thought of as a variable resistor, where the Gate-Source voltage difference can control the Drain-Source Resistance. When there is no applying voltage between the Gate-Source , the Drain-Source resistance is very high, which is almost like a open circuit, so no current may flow through the Drain-Source. When Gate-Source potential difference is applied, the Drain-Source resistance is reduced, and there will be current flowing through Drain-Source, which is now a closed circuit.

ATmega328p is used as the microcontroller for this project. It is a 8 bit controller, 28 Pins in a PDIP package. This controller has 6 PWM channels and 6 10bit ADC channels. These will be used in this project for controlling and to process feedbacks from the output voltage.

A computer interface will be developed using tcl/tk language with features to manually set a desired voltage, to perform a voltage sweep within a specified range and with specific intervals and specific step sizes. Output voltage will also be displayed in the interface.

1

MEL 5450:Embedded Systems Project

## 2. Targets

The main targets to be achieved to complete the project are:

- Building an AC - DC power supply with an output of about 40VDC
- Build a DC-DC buck converter with digital control
- Designing a microcontroller based control system
- Designing a computer GUI for user control

## 3. Methodology

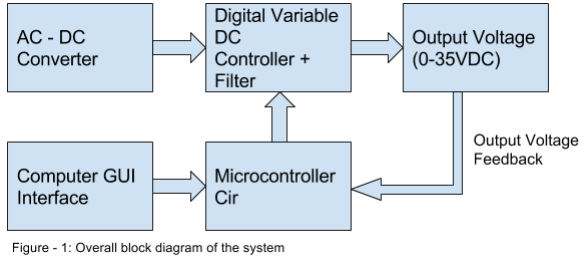
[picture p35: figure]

Figure - 1 shows the overall block diagram. An AC - DC converter will be built to supply a fixed DC output. The output from the rectifier will be applied to the regulating circuit. A MOSFET is used for regulating the voltage. A MOSFET is used for this purpose as it can be controlled digital and more accurately using PWM signals. Output filters will be used to produce a clean DC signal as output from the MOSFET will not be a DC signal. ATmega328p is used as the microcontroller. This acts as the interface between the computer and the power supply. The ATmega328p also takes feedback from the output to verify the correct voltage is being produced and also to display the output voltage to the user. A GUI interface will be designed in the computer for the user to interact, the GUI will include features to do a voltage sweep in desired step sizes and desired intervals. A seven segment display will be included in the circuit to display the output voltage for ease of use.

2

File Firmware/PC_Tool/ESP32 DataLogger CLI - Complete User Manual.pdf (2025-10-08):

# ESP32 DataLogger CLI - Complete User Manual

## Table of Contents

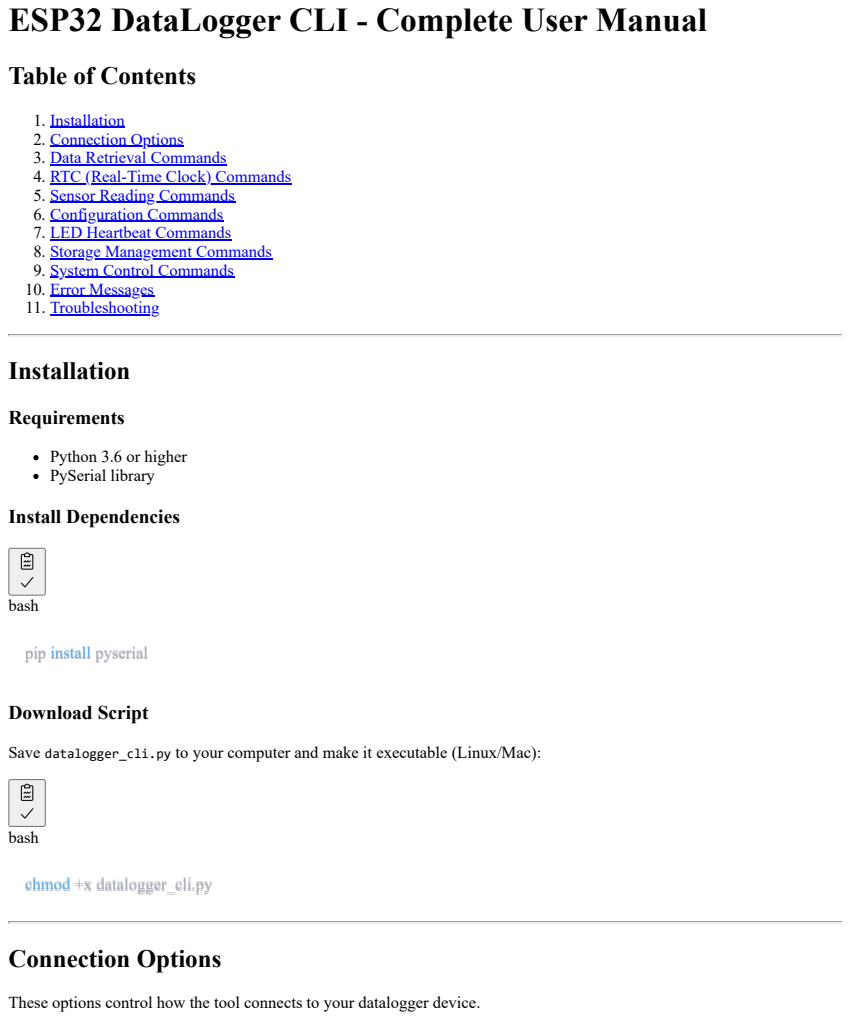
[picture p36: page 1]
Installation; Requirements; bash; Download Script; chmod +x datalogger_cli.py; Connection Options

1. Installation
2. Connection Options
3. Data Retrieval Commands
4. RTC (Real-Time Clock) Commands
5. Sensor Reading Commands
6. Configuration Commands
7. LED Heartbeat Commands
8. Storage Management Commands
9. System Control Commands
10. Error Messages
11. Troubleshooting

Python 3.6 or higher
PySerial library
Install Dependencies

pip install pyserial

Save datalogger_cli.py to your computer and make it executable (Linux/Mac):

These options control how the tool connects to your datalogger device.

--port <PORT>

Description: Specify the serial port to connect to.

Usage:

bash

# Windows

python datalogger_cli.py --port COM19 --list

# Linux

python datalogger_cli.py --port /dev/ttyUSB0 --list

# Mac

python datalogger_cli.py --port /dev/cu.usbserial-XXX --list

When to use:

When auto-discovery fails
When you have multiple devices
For scripts requiring explicit port control

Default: Auto-discovery enabled (no port needed)

--baud <RATE>

Description: Set the serial communication baud rate.

Usage:

bash

python datalogger_cli.py --port COM19 --baud 115200 --list

Default: 115200 (matches firmware default)

Note: Only change if your firmware uses a different baud rate.

--discover / --no-discover

Description: Enable or disable automatic device discovery.

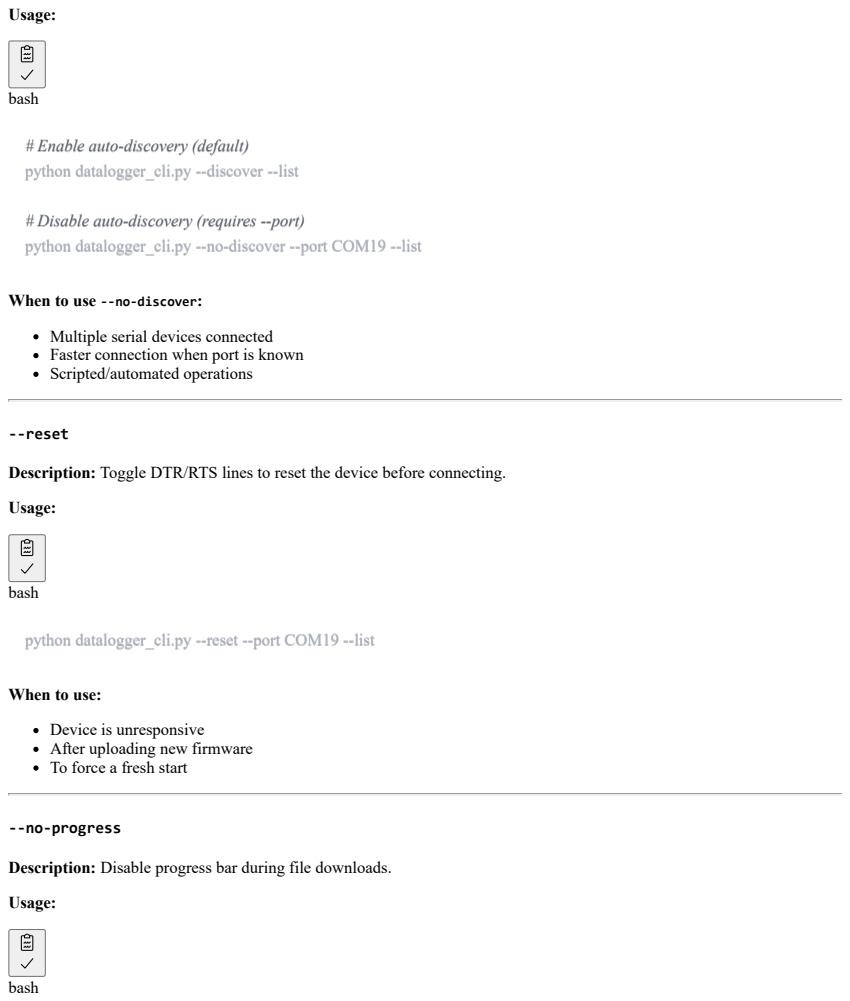
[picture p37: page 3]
Usage:; bash; --reset; --no-progress

# Enable auto-discovery (default)
python datalogger_cli.py --discover --list

# Disable auto-discovery (requires --port)
python datalogger_cli.py --no-discover --port COM19 --list

When to use --no-discover:
Multiple serial devices connected
Faster connection when port is known
Scripted/automated operations

Description: Toggle DTR/RTS lines to reset the device before connecting.
Usage:

python datalogger_cli.py --reset --port COM19 --list

When to use:
Device is unresponsive
After uploading new firmware
To force a fresh start

Description: Disable progress bar during file downloads.

## Data Retrieval Commands

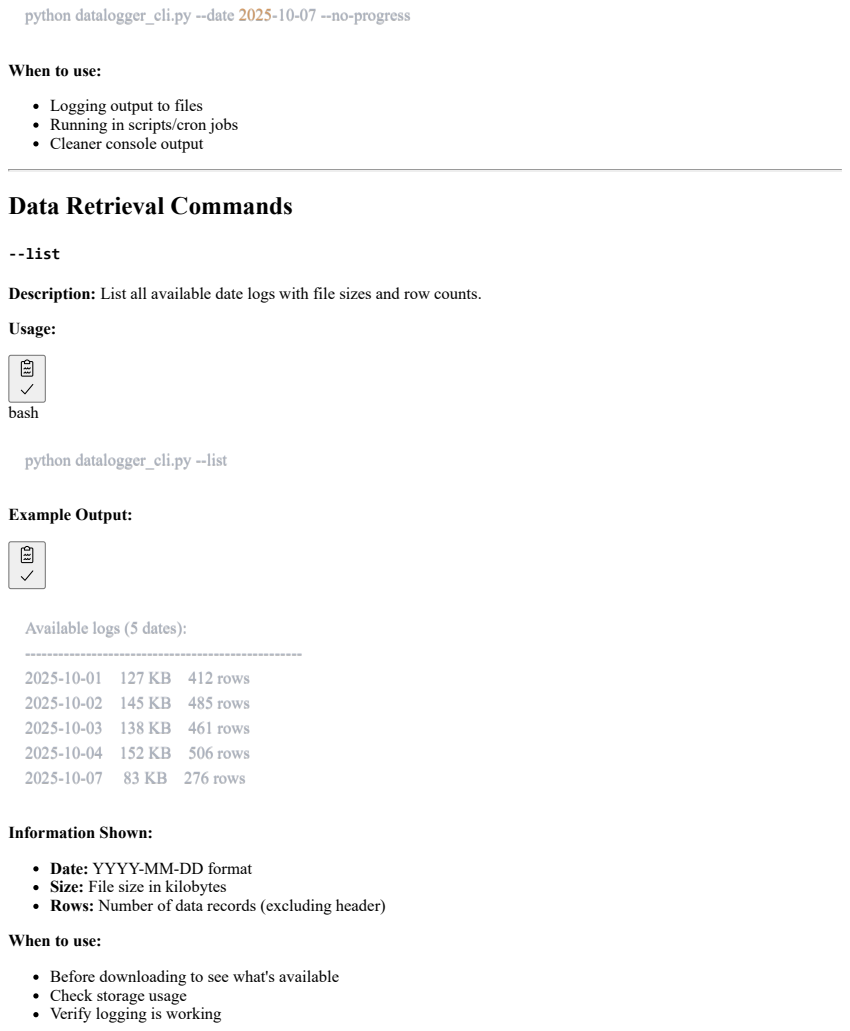
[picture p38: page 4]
--list; bash; Example Output:

python datalogger_cli.py --date 2025-10-07 --no-progress

When to use:
Logging output to files
Running in scripts/cron jobs
Cleaner console output

Description: List all available date logs with file sizes and row counts.
Usage:

python datalogger_cli.py --list

Available logs (5 dates):
2025-10-01 127 KB 412 rows
2025-10-02 145 KB 485 rows
2025-10-03 138 KB 461 rows
2025-10-04 152 KB 506 rows
2025-10-07 83 KB 276 rows

Information Shown:
Date: YYYY-MM-DD format
Size: File size in kilobytes
Rows: Number of data records (excluding header)
Before downloading to see what's available
Check storage usage
Verify logging is working

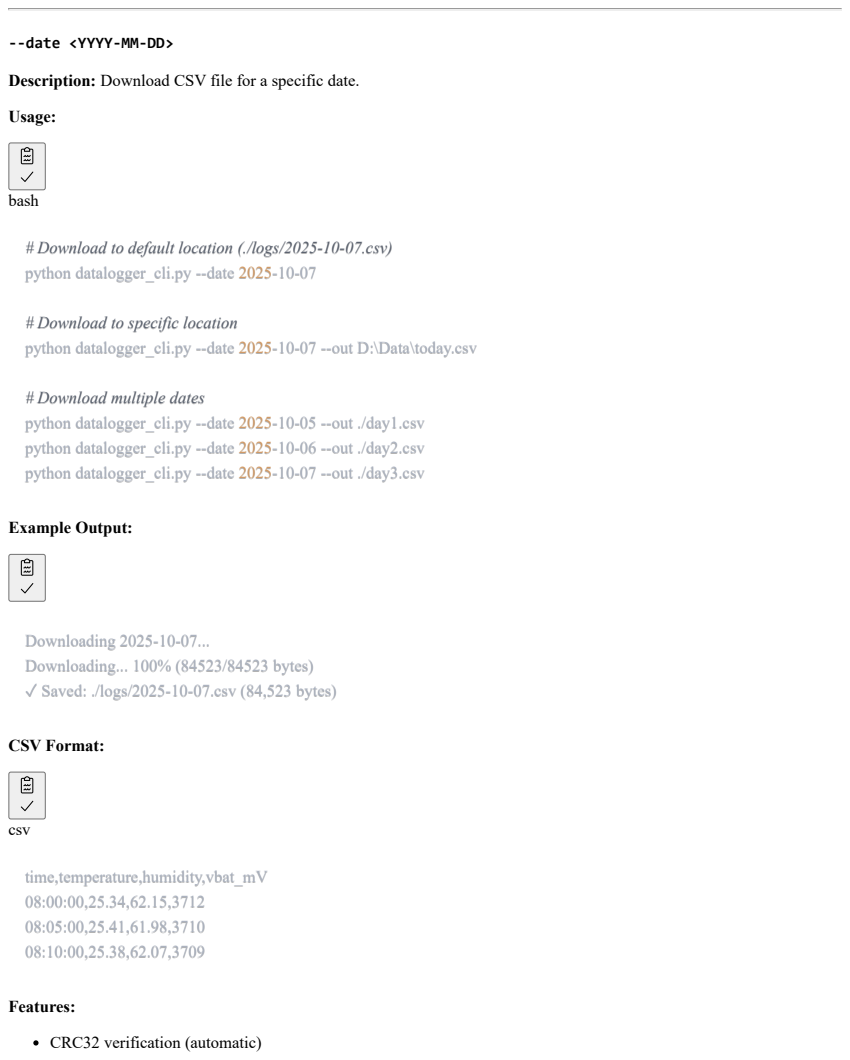
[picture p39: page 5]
bash; Example Output:; CSV Format:; csv; time,temperature,humidity,vbat_mV 08:00:00,25.34,62.15,3712 08:05:00,25.41,61.98,3710 08:10:00,25.38,62.07,3709; Features:; CRC32 verification (automatic)

--date <YYYY-MM-DD>

Description: Download CSV file for a specific date.
Usage:

# Download to default location (./logs/2025-10-07.csv)
python datalogger_cli.py --date 2025-10-07

# Download to specific location
python datalogger_cli.py --date 2025-10-07 --out D:\Data\today.csv

# Download multiple dates
python datalogger_cli.py --date 2025-10-05 --out ./day1.csv
python datalogger_cli.py --date 2025-10-06 --out ./day2.csv
python datalogger_cli.py --date 2025-10-07 --out ./day3.csv

Downloading 2025-10-07...
Downloading... 100% (84523/84523 bytes)
✓ Saved: ./logs/2025-10-07.csv (84,523 bytes)

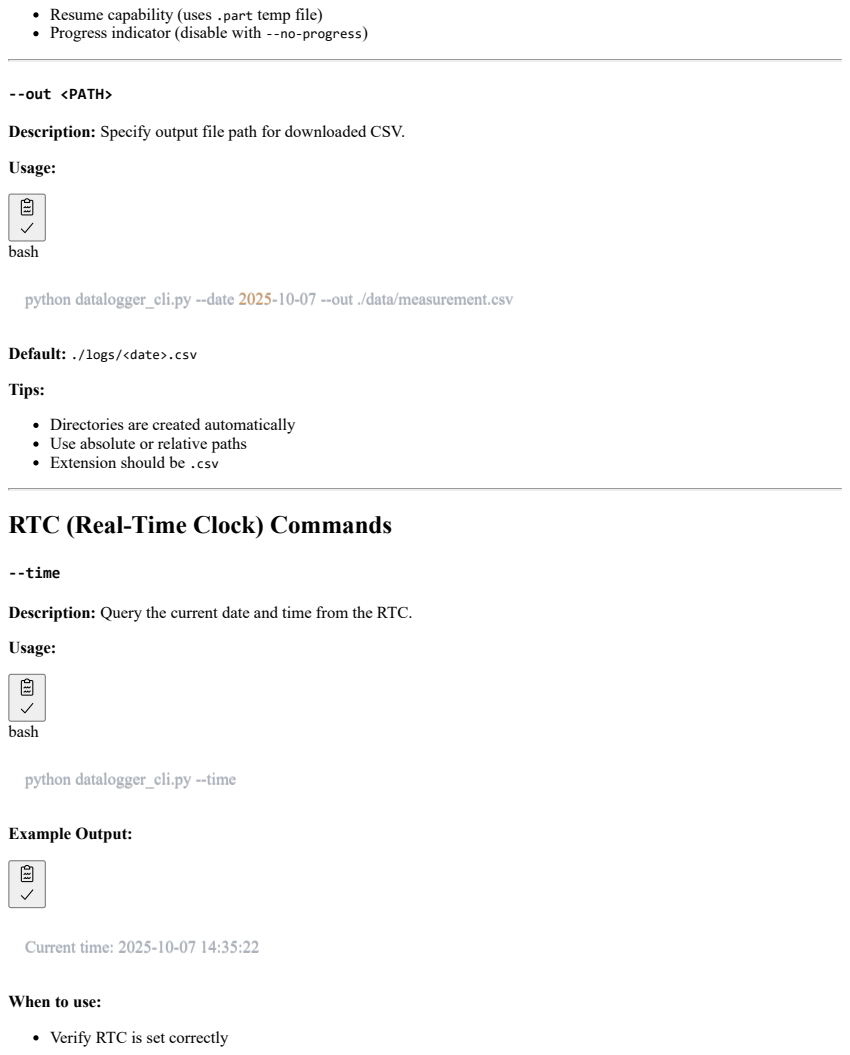
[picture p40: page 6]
--out <PATH>; bash; --time; Example Output:; Current time: 2025-10-07 14:35:22

Resume capability (uses .part temp file)
Progress indicator (disable with --no-progress)

Description: Specify output file path for downloaded CSV.
Usage:

python datalogger_cli.py --date 2025-10-07 --out ./data/measurement.csv

Default: ./logs/<date>.csv
Tips:
Directories are created automatically
Use absolute or relative paths
Extension should be .csv

RTC (Real-Time Clock) Commands

Description: Query the current date and time from the RTC.

python datalogger_cli.py --time

When to use:
Verify RTC is set correctly

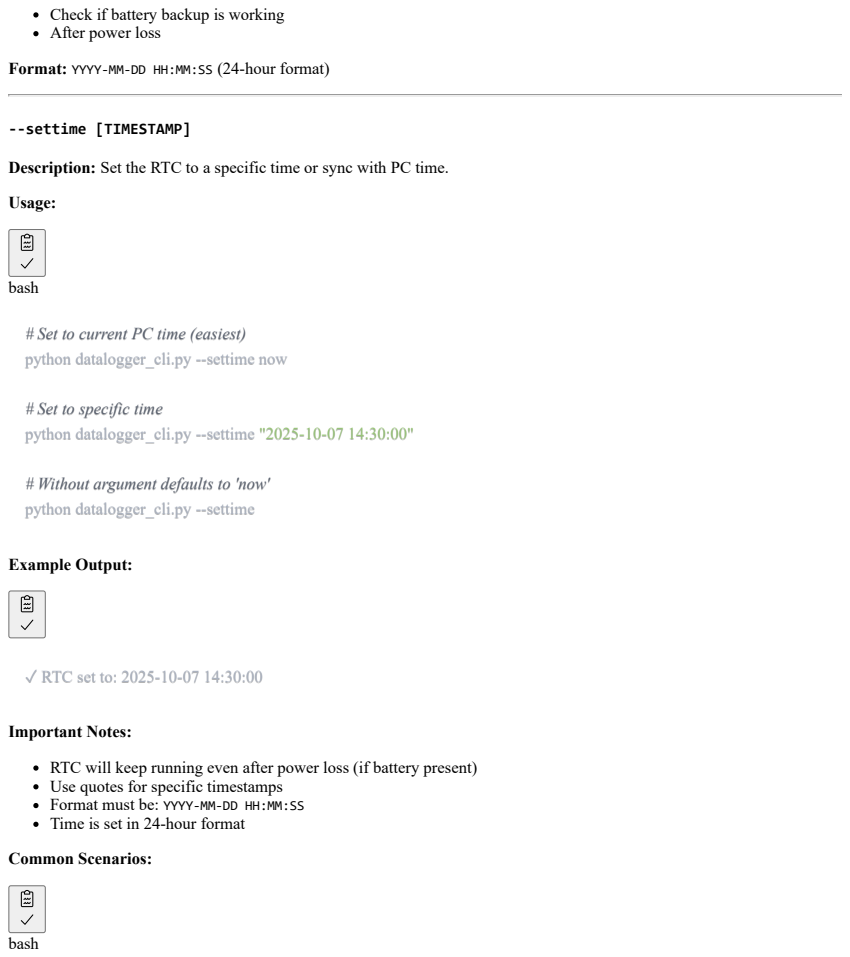
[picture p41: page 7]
--settime [TIMESTAMP]; bash; Example Output:

Check if battery backup is working
After power loss
Format: YYYY-MM-DD HH:MM:SS (24-hour format)

Description: Set the RTC to a specific time or sync with PC time.
Usage:

# Set to current PC time (easiest)
python datalogger_cli.py --settime now

# Set to specific time
python datalogger_cli.py --settime "2025-10-07 14:30:00"

# Without argument defaults to 'now'
python datalogger_cli.py --settime

✓ RTC set to: 2025-10-07 14:30:00

Important Notes:
RTC will keep running even after power loss (if battery present)
Use quotes for specific timestamps
Format must be: YYYY-MM-DD HH:MM:SS
Time is set in 24-hour format
Common Scenarios:

# Initial setup
python datalogger_cli.py --settime now

# After battery replacement

# Set to specific moment (e.g., experiment start)
python datalogger_cli.py --settime "2025-10-07 09:00:00"

Sensor Reading Commands

Description: Read current temperature, humidity, and battery voltage.
Usage:

python datalogger_cli.py --sense

Sensor Details:
Temperature: SHT4x sensor, ±0.2°C accuracy
Humidity: SHT4x sensor, ±2% RH accuracy
Battery: Voltage divider measurement
When to use:
Quick health check
Verify sensors are working
Monitor battery level
Check environmental conditions

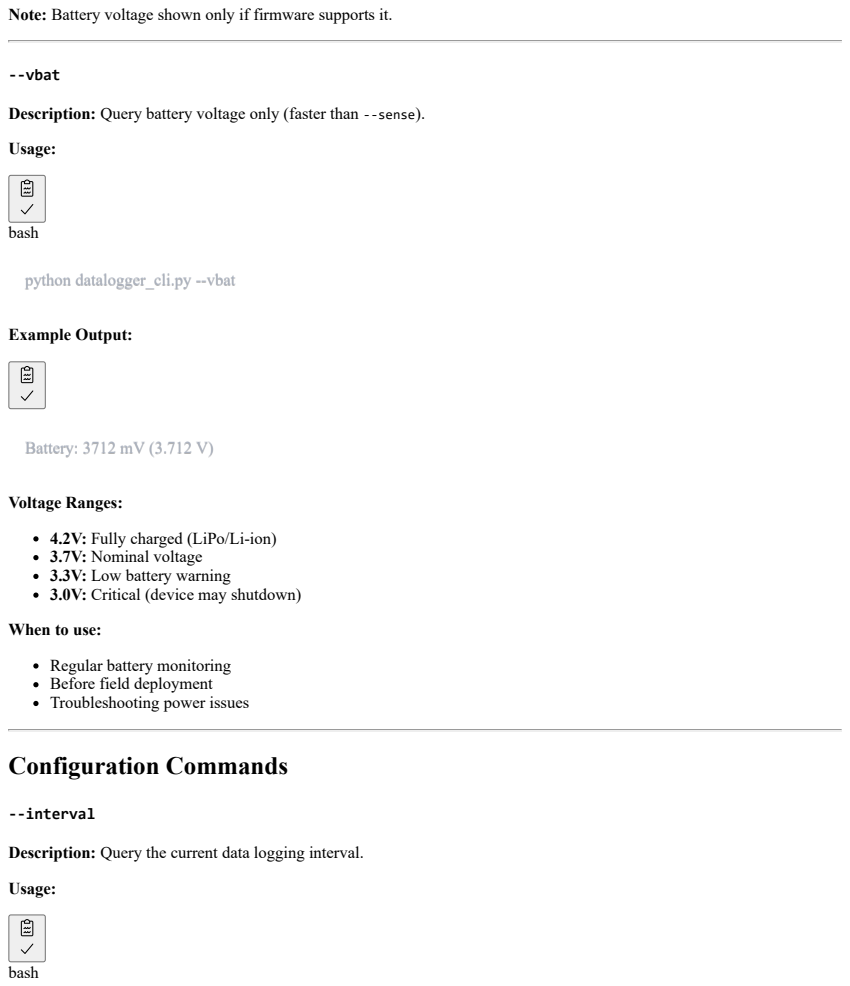
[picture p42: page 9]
--vbat; bash; Example Output:; Battery: 3712 mV (3.712 V); Configuration Commands; --interval

Note: Battery voltage shown only if firmware supports it.

Description: Query battery voltage only (faster than --sense).
Usage:

python datalogger_cli.py --vbat

Voltage Ranges:
4.2V: Fully charged (LiPo/Li-ion)
3.7V: Nominal voltage
3.3V: Low battery warning
3.0V: Critical (device may shutdown)
When to use:
Regular battery monitoring
Before field deployment
Troubleshooting power issues

Description: Query the current data logging interval.

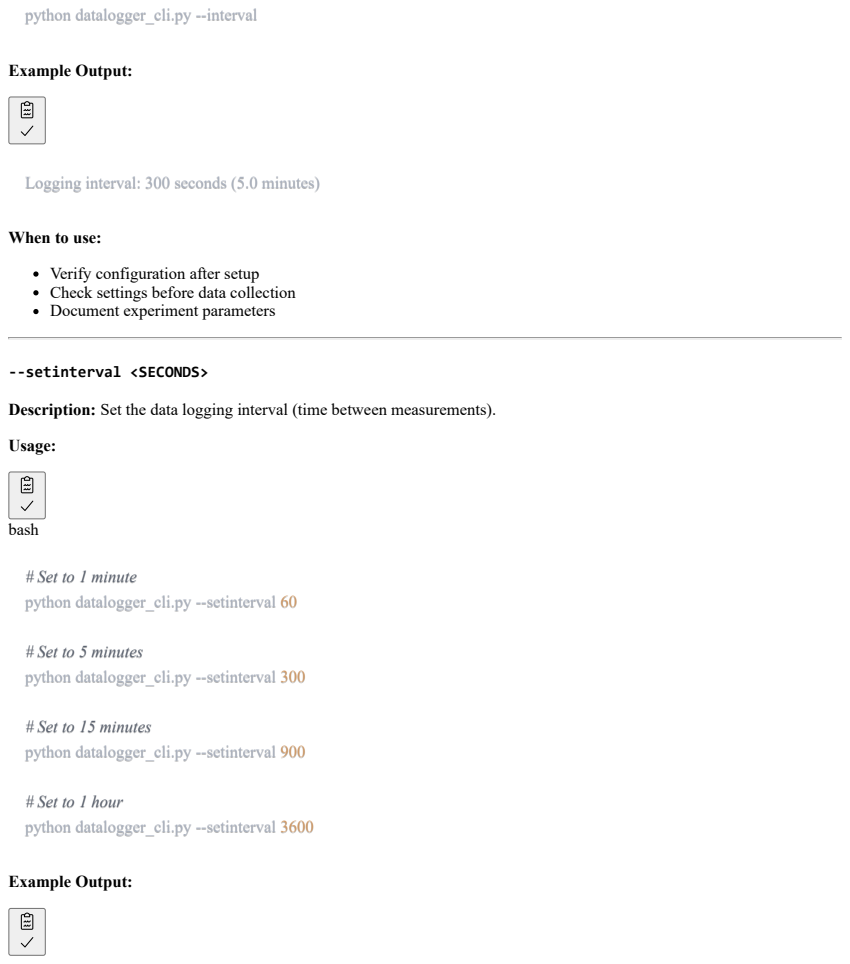
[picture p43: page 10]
Example Output:; --setinterval <SECONDS>; bash

python datalogger_cli.py --interval

Logging interval: 300 seconds (5.0 minutes)

When to use:
Verify configuration after setup
Check settings before data collection
Document experiment parameters

Description: Set the data logging interval (time between measurements).
Usage:

# Set to 1 minute
python datalogger_cli.py --setinterval 60

# Set to 5 minutes
python datalogger_cli.py --setinterval 300

# Set to 15 minutes
python datalogger_cli.py --setinterval 900

# Set to 1 hour
python datalogger_cli.py --setinterval 3600

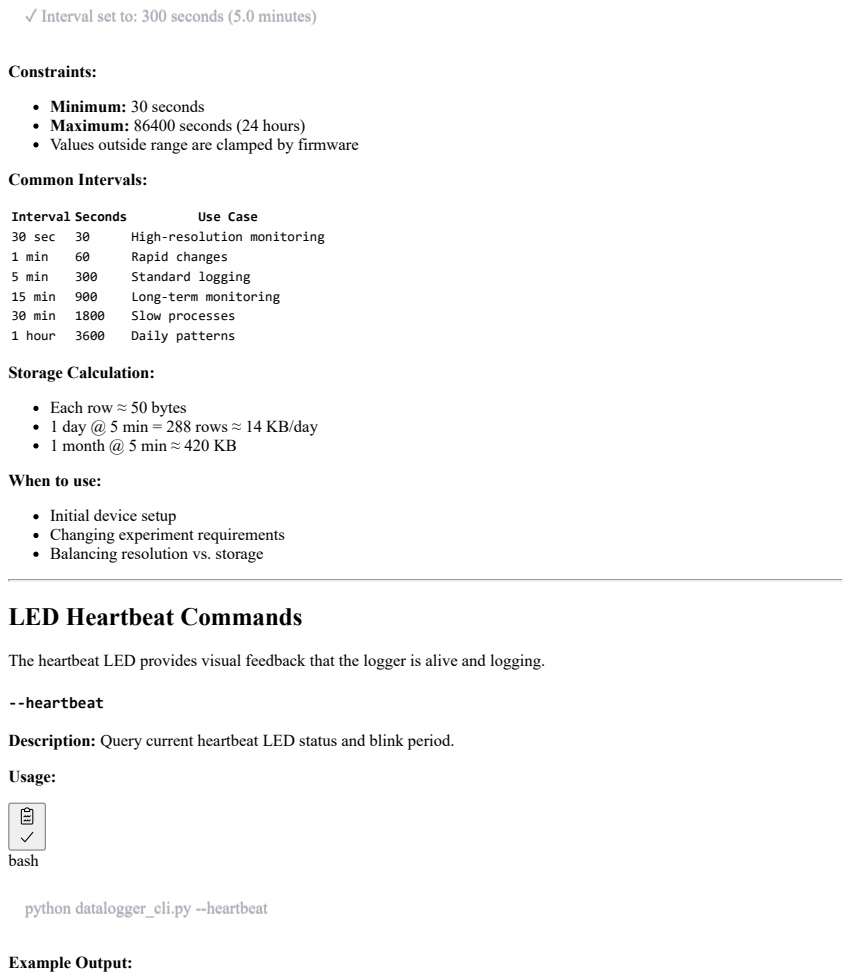
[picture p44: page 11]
Interval Seconds; Use Case; 30 sec; High-resolution monitoring; 1 min; Rapid changes; 5 min; Standard logging; 15 min; Long-term monitoring; 30 min; Slow processes; 1 hour; Daily patterns; --heartbeat; bash; Example Output:

✓ Interval set to: 300 seconds (5.0 minutes)

Constraints:
Minimum: 30 seconds
Maximum: 86400 seconds (24 hours)
Values outside range are clamped by firmware
Common Intervals:

Storage Calculation:
Each row ≈ 50 bytes
1 day @ 5 min = 288 rows ≈ 14 KB/day
1 month @ 5 min ≈ 420 KB
When to use:
Initial device setup
Changing experiment requirements
Balancing resolution vs. storage

LED Heartbeat Commands

The heartbeat LED provides visual feedback that the logger is alive and logging.

Description: Query current heartbeat LED status and blink period.
Usage:

python datalogger_cli.py --heartbeat

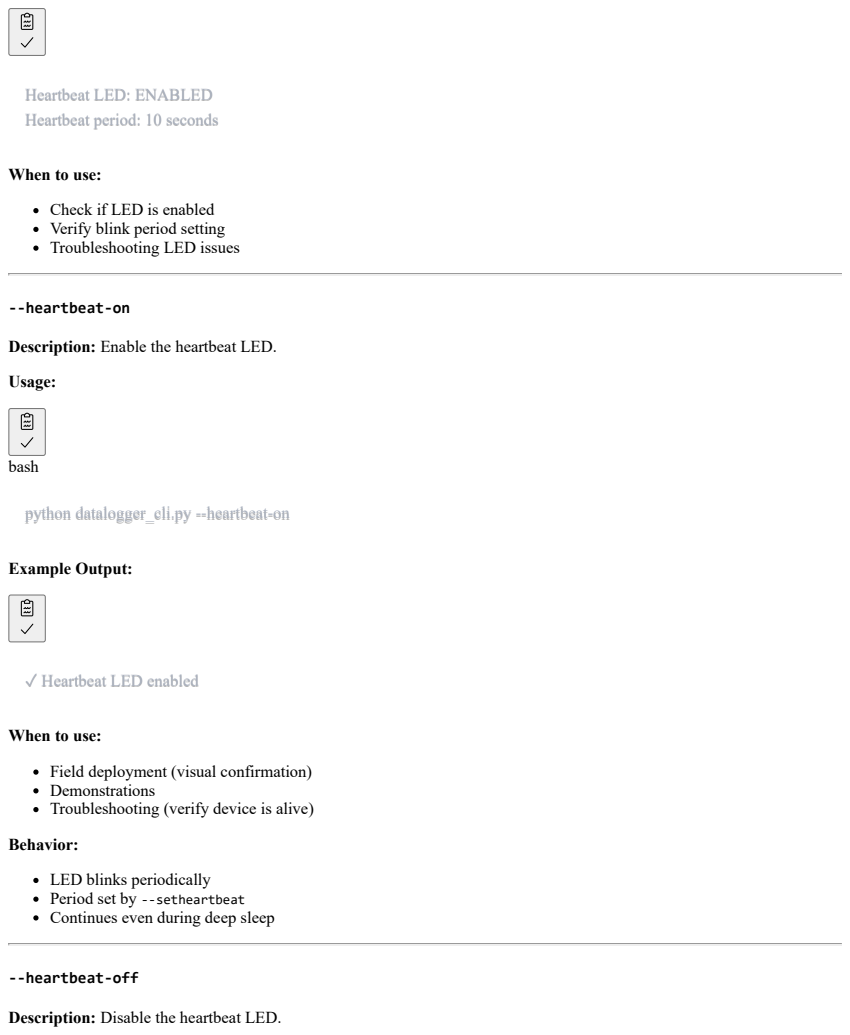
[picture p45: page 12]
--heartbeat-on; bash; Example Output:; --heartbeat-off

Heartbeat LED: ENABLED
Heartbeat period: 10 seconds

When to use:
Check if LED is enabled
Verify blink period setting
Troubleshooting LED issues

Description: Enable the heartbeat LED.
Usage:

python datalogger_cli.py --heartbeat-on

✓ Heartbeat LED enabled

Field deployment (visual confirmation)
Demonstrations
Troubleshooting (verify device is alive)
Behavior:
LED blinks periodically
Period set by --setheartbeat
Continues even during deep sleep

Description: Disable the heartbeat LED.

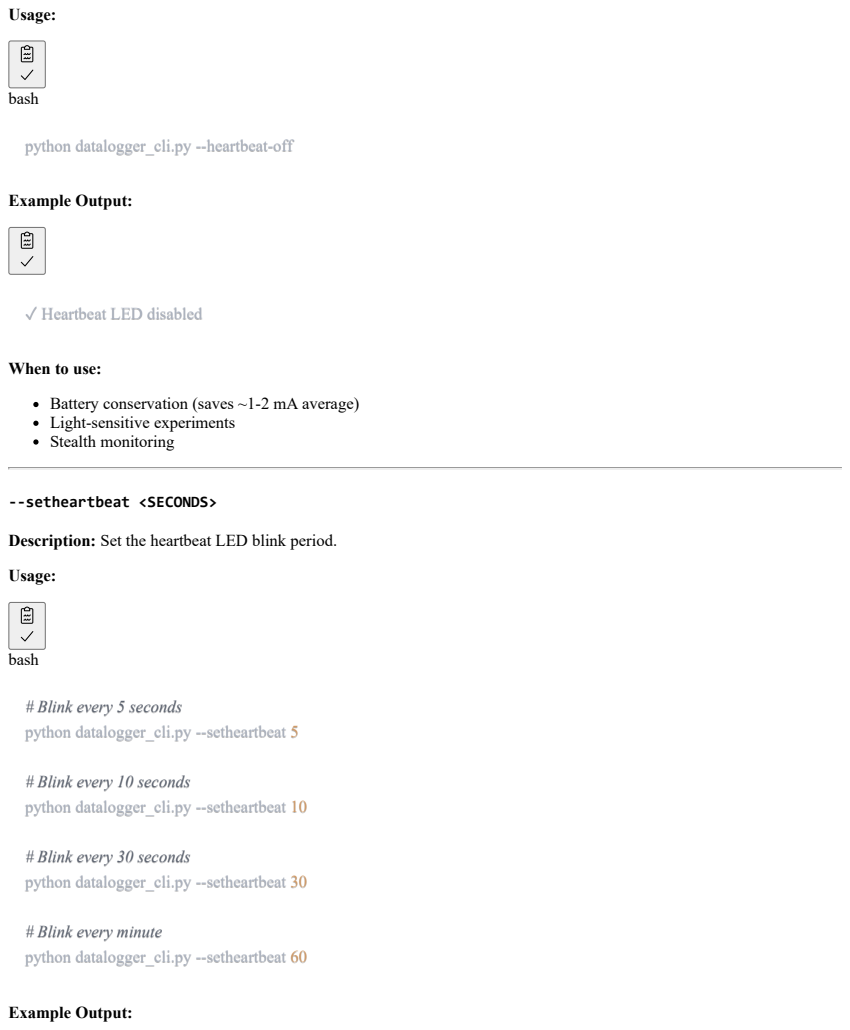
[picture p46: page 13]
Usage:; bash; Example Output:; --setheartbeat <SECONDS>

python datalogger_cli.py --heartbeat-off

✓ Heartbeat LED disabled

When to use:
Battery conservation (saves ~1-2 mA average)
Light-sensitive experiments
Stealth monitoring

Description: Set the heartbeat LED blink period.
Usage:

# Blink every 5 seconds
python datalogger_cli.py --setheartbeat 5

# Blink every 10 seconds
python datalogger_cli.py --setheartbeat 10

# Blink every 30 seconds
python datalogger_cli.py --setheartbeat 30

# Blink every minute
python datalogger_cli.py --setheartbeat 60

✓ Heartbeat period set to: 10 seconds

Recommended Periods:
5 seconds: High visibility (uses more power)
10 seconds: Balanced (default)
30 seconds: Low power
60 seconds: Ultra low power
Power Impact:
Shorter period = more blinks = more power
Each blink ≈ 20mA for ~100ms

Storage Management Commands

Description: Display complete flash partition table.
Usage:

python datalogger_cli.py --flash-info

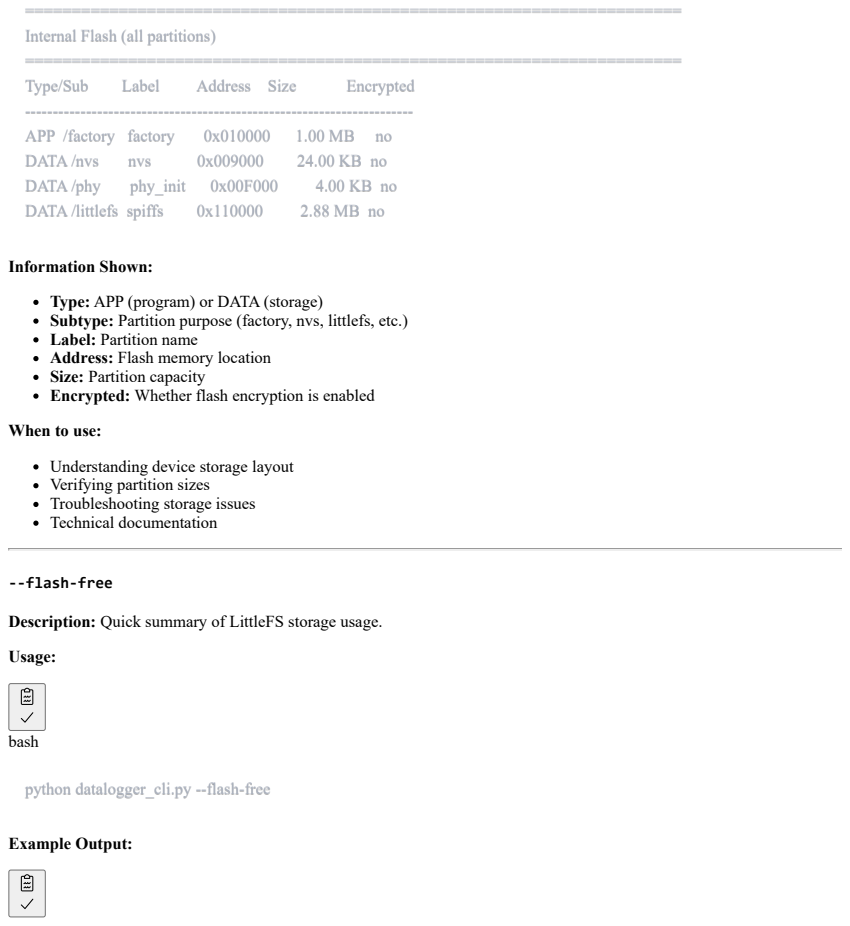
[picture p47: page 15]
====================================================================== Internal Flash (all partitions) ======================================================================; Type/Sub; Label; Address Size; Encrypted; APP /factory factory; DATA /nvs; nvs; DATA /phy; phy_init; DADATTAA /littlefs spif /littlefs spiffs; --flash-free; bash; Example Output:

Information Shown:
Type: APP (program) or DATA (storage)
Subtype: Partition purpose (factory, nvs, littlefs, etc.)
Label: Partition name
Address: Flash memory location
Size: Partition capacity
Encrypted: Whether flash encryption is enabled
When to use:
Understanding device storage layout
Verifying partition sizes
Troubleshooting storage issues
Technical documentation

Description: Quick summary of LittleFS storage usage.
Usage:

python datalogger_cli.py --flash-free

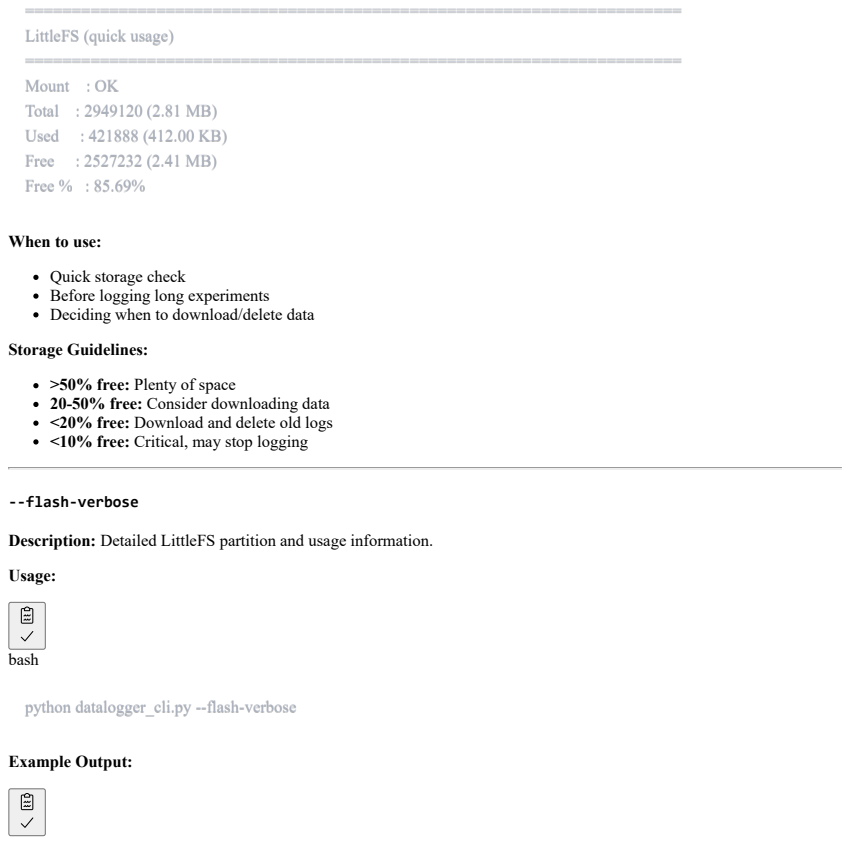
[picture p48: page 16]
--flash-verbose; bash; Example Output:

LittleFS (quick usage)
Mount : OK
Total : 2949120 (2.81 MB)
Used : 421888 (412.00 KB)
Free : 2527232 (2.41 MB)
Free % : 85.69%

When to use:
Quick storage check
Before logging long experiments
Deciding when to download/delete data
Storage Guidelines:
>50% free: Plenty of space
20-50% free: Consider downloading data
<20% free: Download and delete old logs
<10% free: Critical, may stop logging

Description: Detailed LittleFS partition and usage information.
Usage:

python datalogger_cli.py --flash-verbose

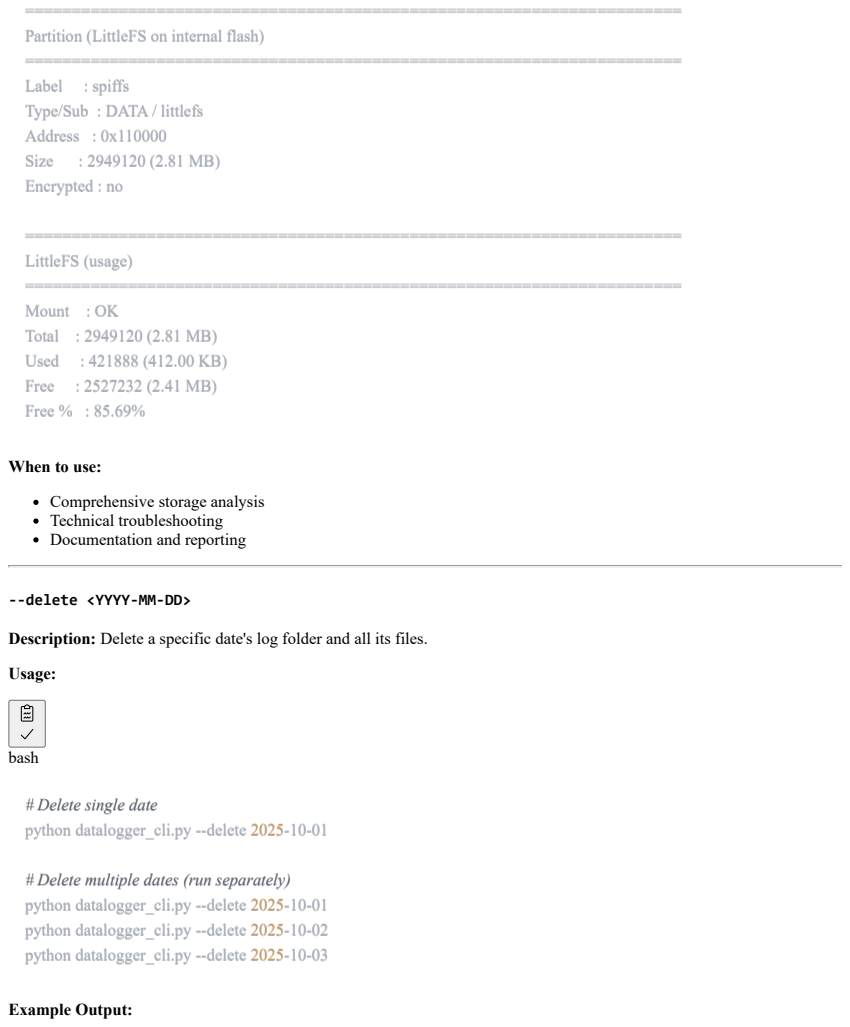
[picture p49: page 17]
Size; ====================================================================== LittleFS (usage) ====================================================================== Mount : OK Total : 2949120 (2.81 MB) Used : 421888 (412.00 KB) Free : 2527232 (2.41 MB) Free % : 85.69%; bash; Example Output:

Partition (LittleFS on internal flash)
Label : spiffs
Type/Sub : DATA / littlefs
Address : 0x110000
Encrypted : no

When to use:
Comprehensive storage analysis
Technical troubleshooting
Documentation and reporting

--delete <YYYY-MM-DD>

Description: Delete a specific date's log folder and all its files.
Usage:

# Delete single date
python datalogger_cli.py --delete 2025-10-01

# Delete multiple dates (run separately)
python datalogger_cli.py --delete 2025-10-02
python datalogger_cli.py --delete 2025-10-03

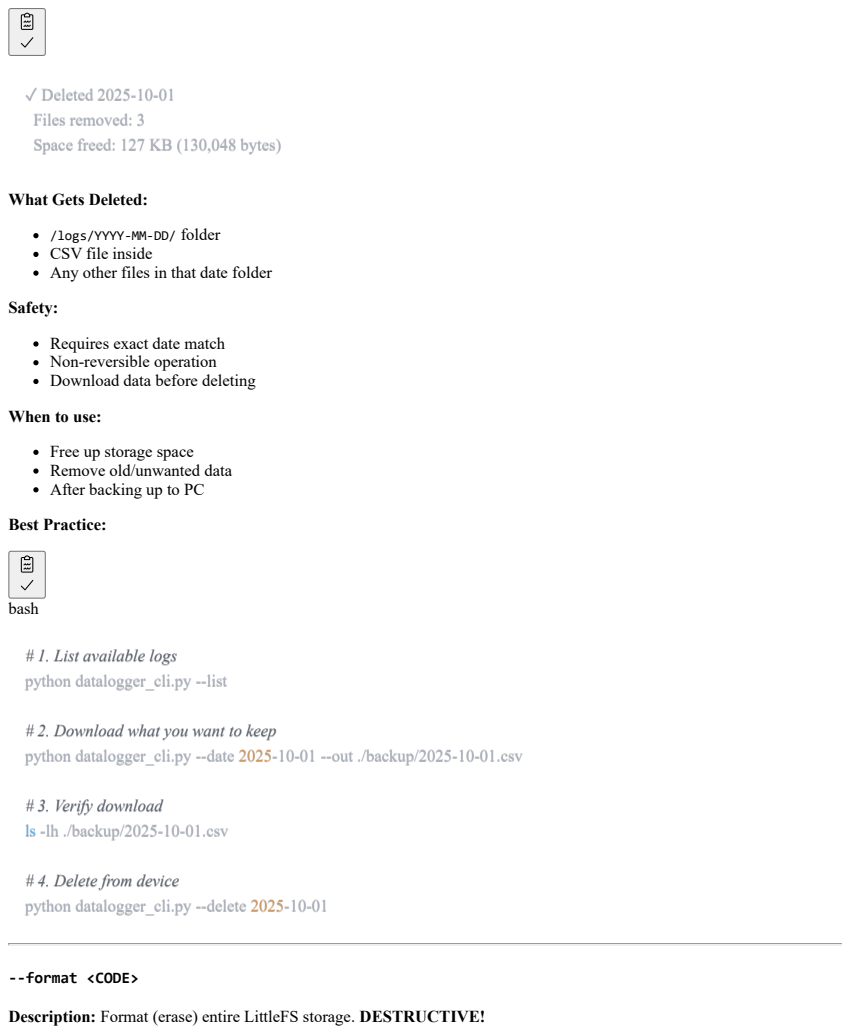
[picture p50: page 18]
bash; --format <CODE>

✓ Deleted 2025-10-01
Files removed: 3
Space freed: 127 KB (130,048 bytes)

What Gets Deleted:

/logs/YYYY-MM-DD/ folder
CSV file inside
Any other files in that date folder
Safety:
Requires exact date match
Non-reversible operation
Download data before deleting
When to use:
Free up storage space
Remove old/unwanted data
After backing up to PC
Best Practice:

# 1. List available logs
python datalogger_cli.py --list

# 2. Download what you want to keep
python datalogger_cli.py --date 2025-10-01 --out ./backup/2025-10-01.csv

# 3. Verify download
ls -lh ./backup/2025-10-01.csv

# 4. Delete from device
python datalogger_cli.py --delete 2025-10-01

Description: Format (erase) entire LittleFS storage. DESTRUCTIVE!

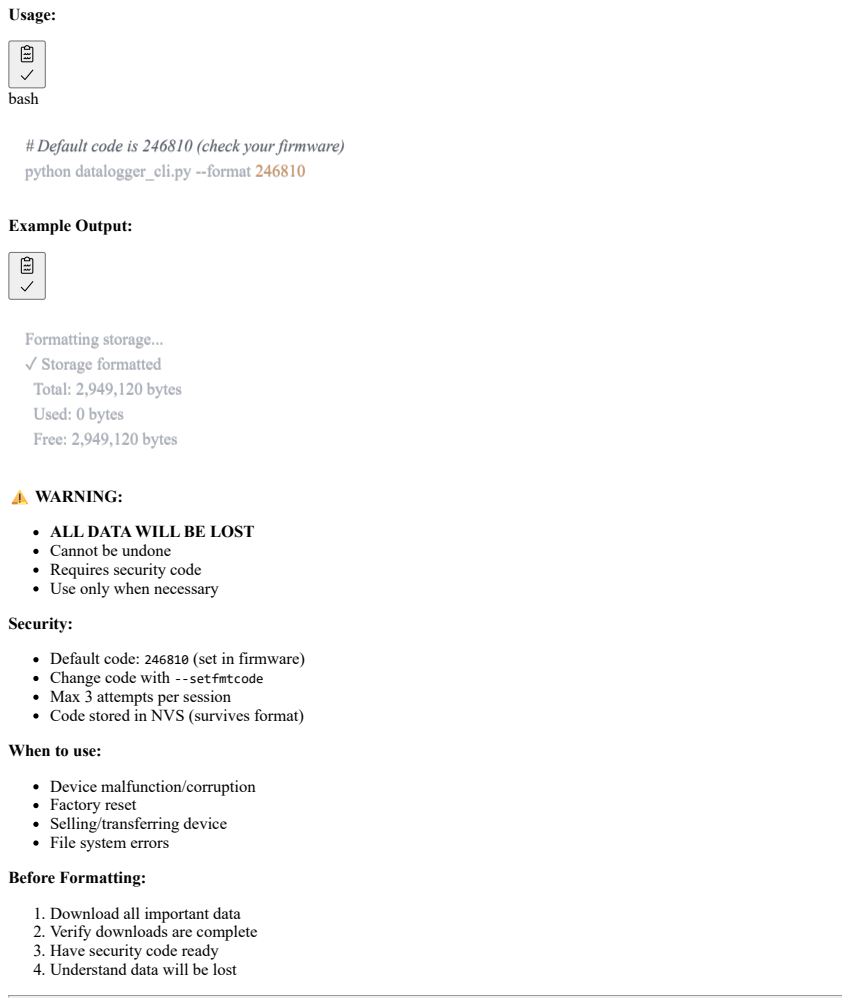
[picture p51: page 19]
Usage:; bash; Example Output:; Formatting storage... ✓ Storage formatted; Total: 2,949,120 bytes Used: 0 bytes Free: 2,949,120 bytes

# Default code is 246810 (check your firmware)
python datalogger_cli.py --format 246810

⚠️ WARNING:
ALL DATA WILL BE LOST
Cannot be undone
Requires security code
Use only when necessary
Security:
Default code: 246810 (set in firmware)
Change code with --setfmtcode
Max 3 attempts per session
Code stored in NVS (survives format)
When to use:
Device malfunction/corruption
Factory reset
Selling/transferring device
File system errors
Before Formatting:
1. Download all important data
2. Verify downloads are complete
3. Have security code ready
4. Understand data will be lost

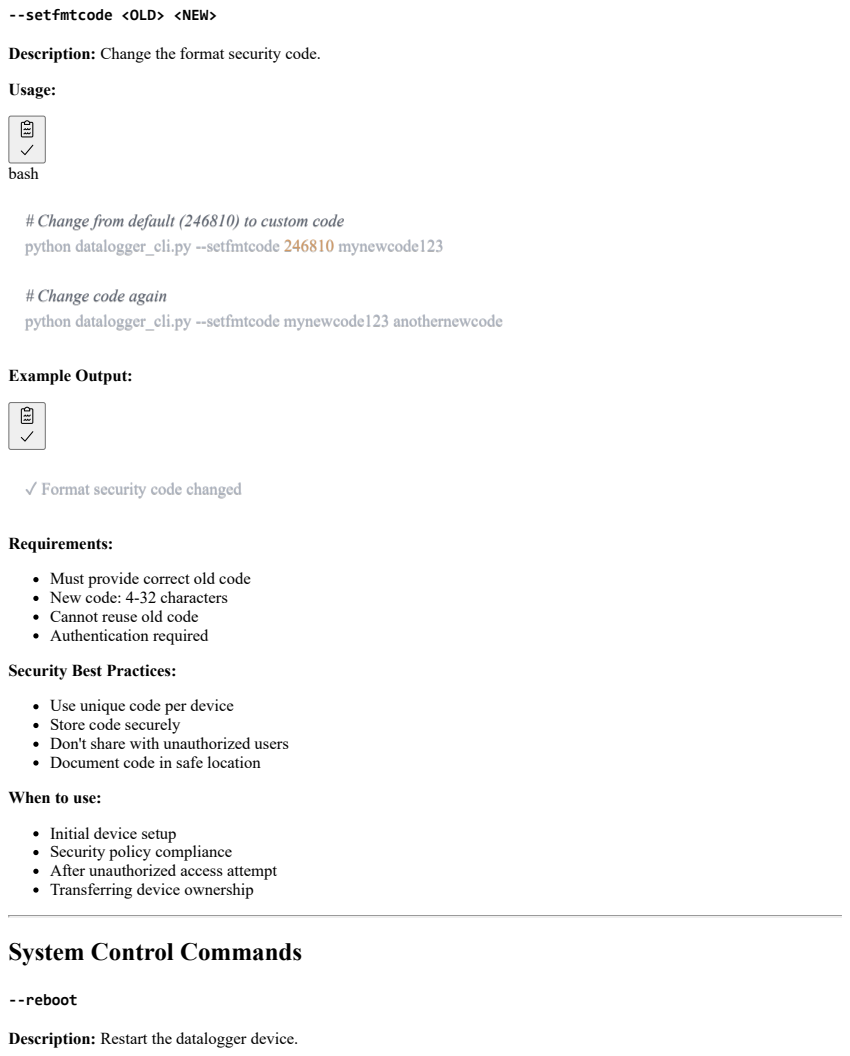
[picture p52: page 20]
bash; Example Output:; --reboot

--setfmtcode <OLD> <NEW>

Description: Change the format security code.
Usage:

# Change from default (246810) to custom code
python datalogger_cli.py --setfmtcode 246810 mynewcode123

# Change code again
python datalogger_cli.py --setfmtcode mynewcode123 anothernewcode

✓ Format security code changed

Requirements:
Must provide correct old code
New code: 4-32 characters
Cannot reuse old code
Authentication required
Security Best Practices:
Use unique code per device
Store code securely
Don't share with unauthorized users
Document code in safe location
When to use:
Initial device setup
Security policy compliance
After unauthorized access attempt
Transferring device ownership

System Control Commands

Description: Restart the datalogger device.

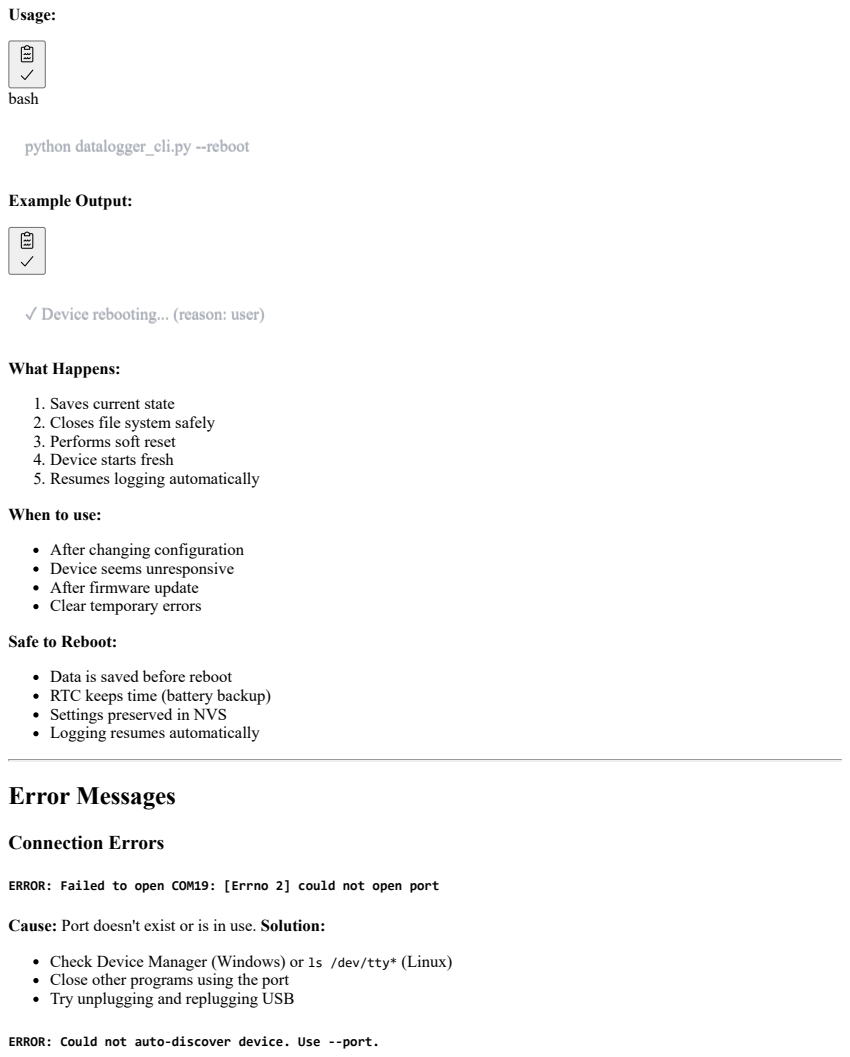
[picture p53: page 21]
Usage:; bash; Example Output:; Error Messages; Connection Errors

python datalogger_cli.py --reboot

✓ Device rebooting... (reason: user)

What Happens:
1. Saves current state
2. Closes file system safely
3. Performs soft reset
4. Device starts fresh
5. Resumes logging automatically
When to use:
After changing configuration
Device seems unresponsive
After firmware update
Clear temporary errors
Safe to Reboot:
Data is saved before reboot
RTC keeps time (battery backup)
Settings preserved in NVS
Logging resumes automatically

ERROR: Failed to open COM19: [Errno 2] could not open port

Cause: Port doesn't exist or is in use. Solution:
Check Device Manager (Windows) or ls /dev/tty* (Linux)
Close other programs using the port
Try unplugging and replugging USB

ERROR: Could not auto-discover device. Use --port.

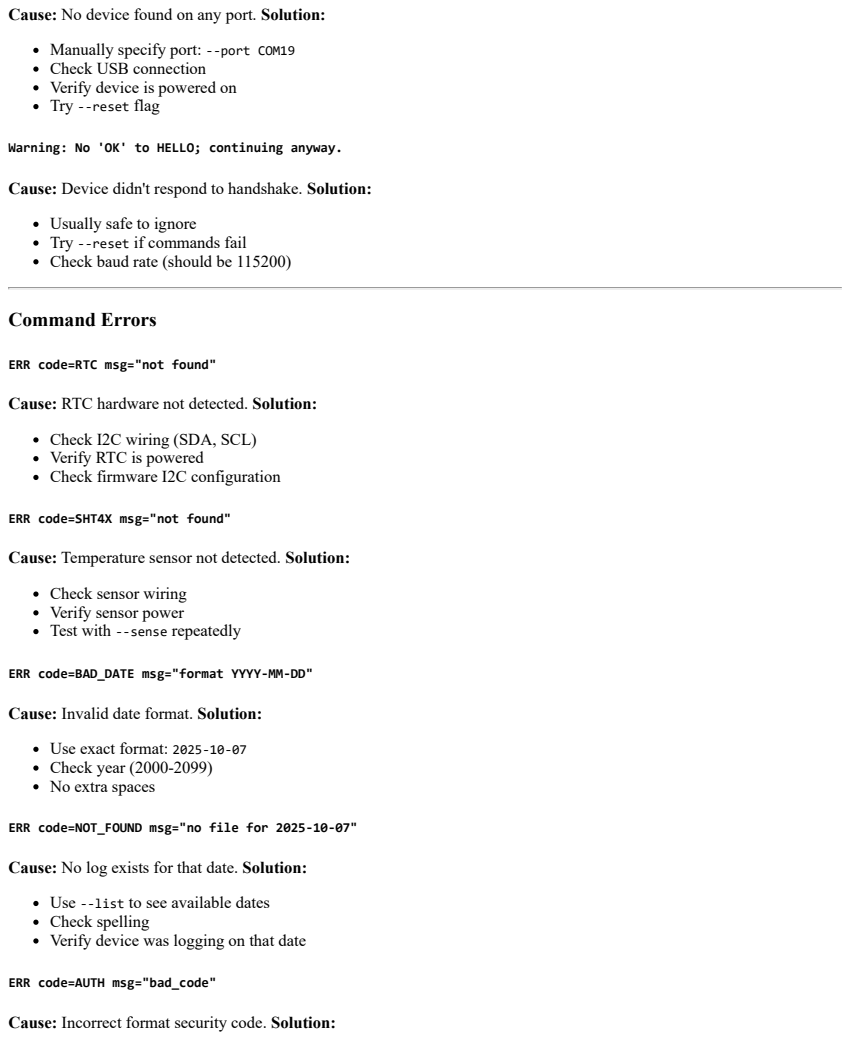
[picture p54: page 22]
Command Errors

Cause: No device found on any port. Solution:
Manually specify port: --port COM19
Check USB connection
Verify device is powered on
Try --reset flag

Warning: No 'OK' to HELLO; continuing anyway.

Cause: Device didn't respond to handshake. Solution:
Usually safe to ignore
Try --reset if commands fail
Check baud rate (should be 115200)

ERR code=RTC msg="not found"

Cause: RTC hardware not detected. Solution:
Check I2C wiring (SDA, SCL)
Verify RTC is powered
Check firmware I2C configuration

ERR code=SHT4X msg="not found"

Cause: Temperature sensor not detected. Solution:
Check sensor wiring
Verify sensor power
Test with --sense repeatedly

ERR code=BAD_DATE msg="format YYYY-MM-DD"

Cause: Invalid date format. Solution:
Use exact format: 2025-10-07
Check year (2000-2099)
No extra spaces

ERR code=NOT_FOUND msg="no file for 2025-10-07"

Cause: No log exists for that date. Solution:
Use --list to see available dates
Check spelling
Verify device was logging on that date

ERR code=AUTH msg="bad_code"

Cause: Incorrect format security code. Solution:

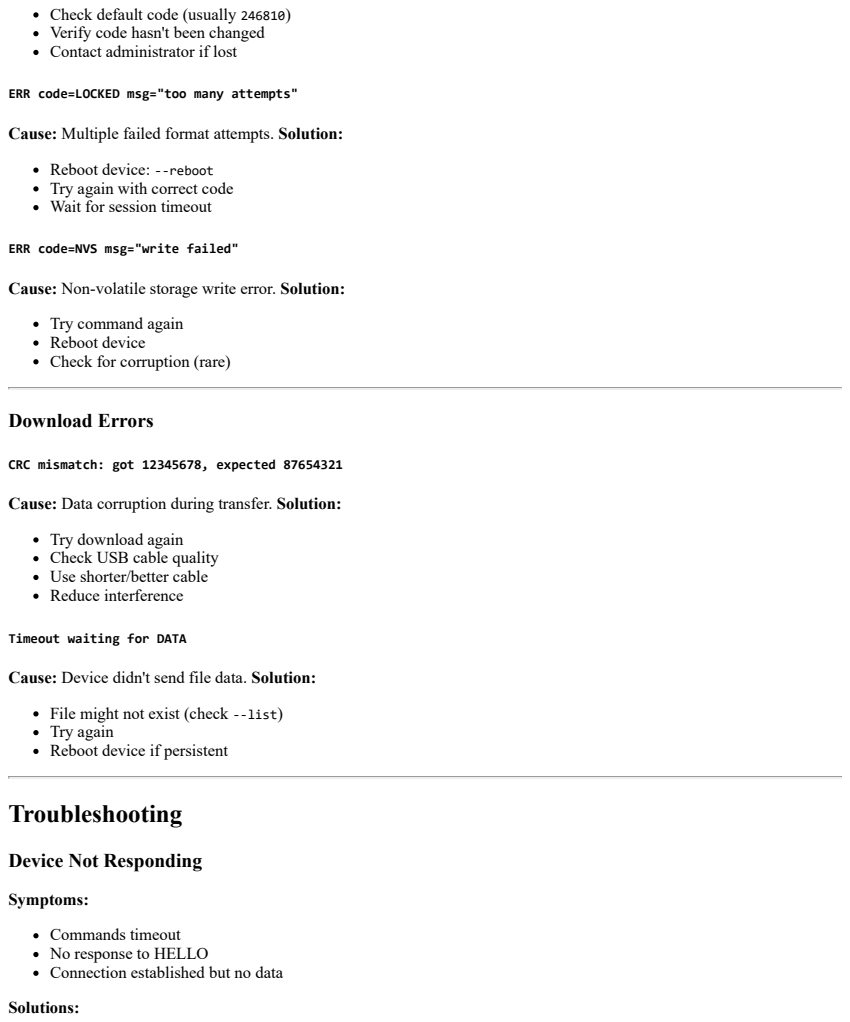
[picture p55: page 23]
Download Errors; Troubleshooting

Check default code (usually 246810)
Verify code hasn't been changed
Contact administrator if lost

ERR code=LOCKED msg="too many attempts"

Cause: Multiple failed format attempts. Solution:
Reboot device: --reboot
Try again with correct code
Wait for session timeout

ERR code=NVS msg="write failed"

Cause: Non-volatile storage write error. Solution:
Try command again
Reboot device
Check for corruption (rare)

CRC mismatch: got 12345678, expected 87654321

Cause: Data corruption during transfer. Solution:
Try download again
Check USB cable quality
Use shorter/better cable
Reduce interference

Timeout waiting for DATA

Cause: Device didn't send file data. Solution:
File might not exist (check --list)
Try again
Reboot device if persistent

Device Not Responding

Symptoms:
Commands timeout
No response to HELLO
Connection established but no data
Solutions:

1. Try hard reset:

python datalogger_cli.py --reset --port COM19 --time

2. Manually reboot device:

python datalogger_cli.py --reboot

python datalogger_cli.py --vbat

If battery < 3.0V, charge/replace
4. Verify port and baud:

python datalogger_cli.py --port COM19 --baud 115200 --list

Symptoms:
Download takes several minutes
Progress bar moves slowly
Causes:
Large files (normal)
USB interference
Poor cable

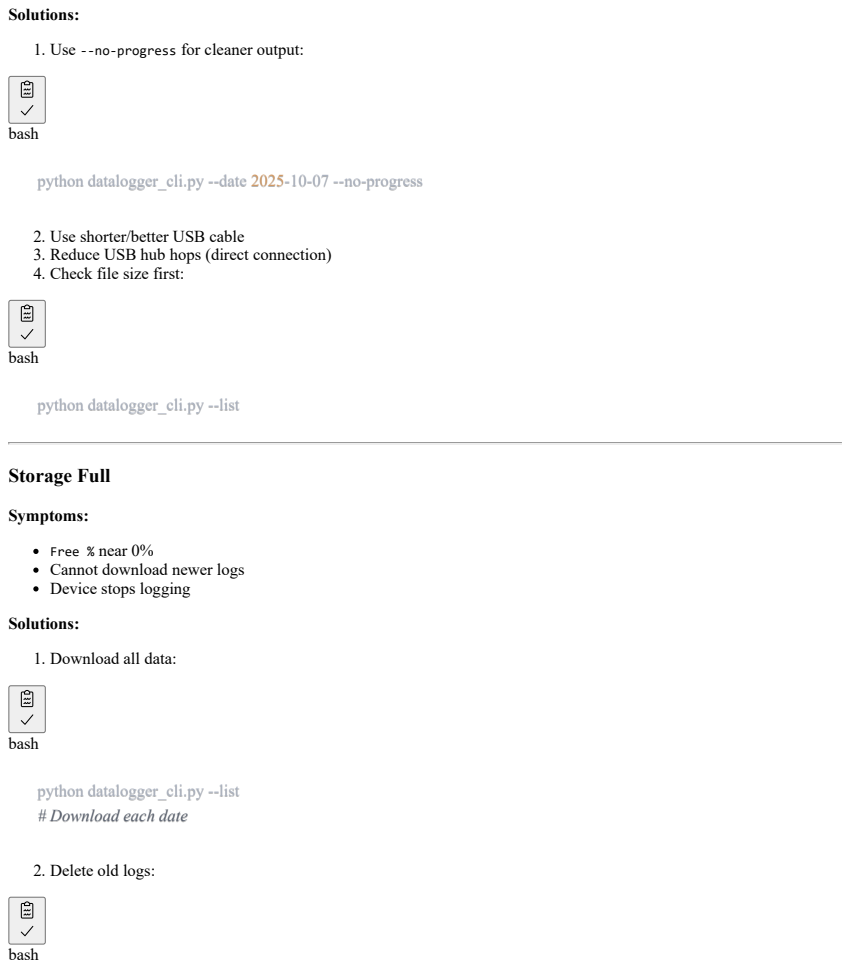
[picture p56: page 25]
bash; Storage Full

Solutions:
1. Use --no-progress for cleaner output:

python datalogger_cli.py --date 2025-10-07 --no-progress

2. Use shorter/better USB cable
3. Reduce USB hub hops (direct connection)
4. Check file size first:

python datalogger_cli.py --list

Symptoms:
Free % near 0%
Cannot download newer logs
Device stops logging
1. Download all data:

# Download each date

2. Delete old logs:

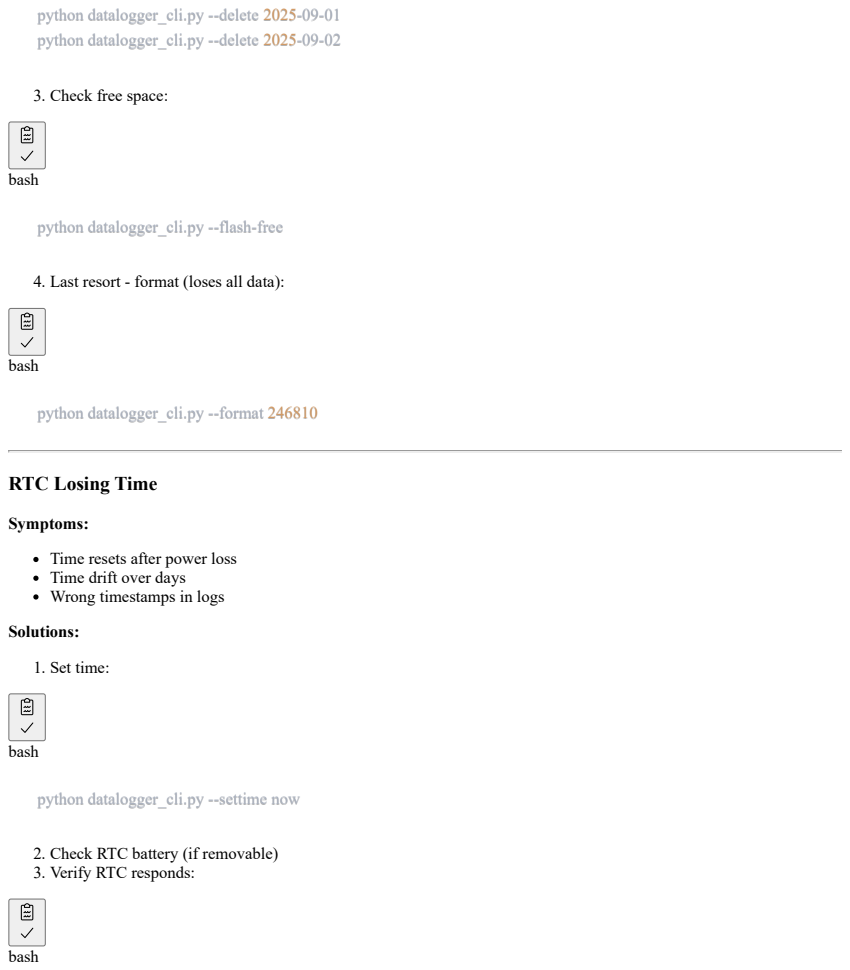
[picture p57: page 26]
bash

python datalogger_cli.py --delete 2025-09-01
python datalogger_cli.py --delete 2025-09-02

3. Check free space:

python datalogger_cli.py --flash-free

4. Last resort - format (loses all data):

python datalogger_cli.py --format 246810

RTC Losing Time

Symptoms:
Time resets after power loss
Time drift over days
Wrong timestamps in logs
Solutions:
1. Set time:

python datalogger_cli.py --settime now

2. Check RTC battery (if removable)
3. Verify RTC responds:

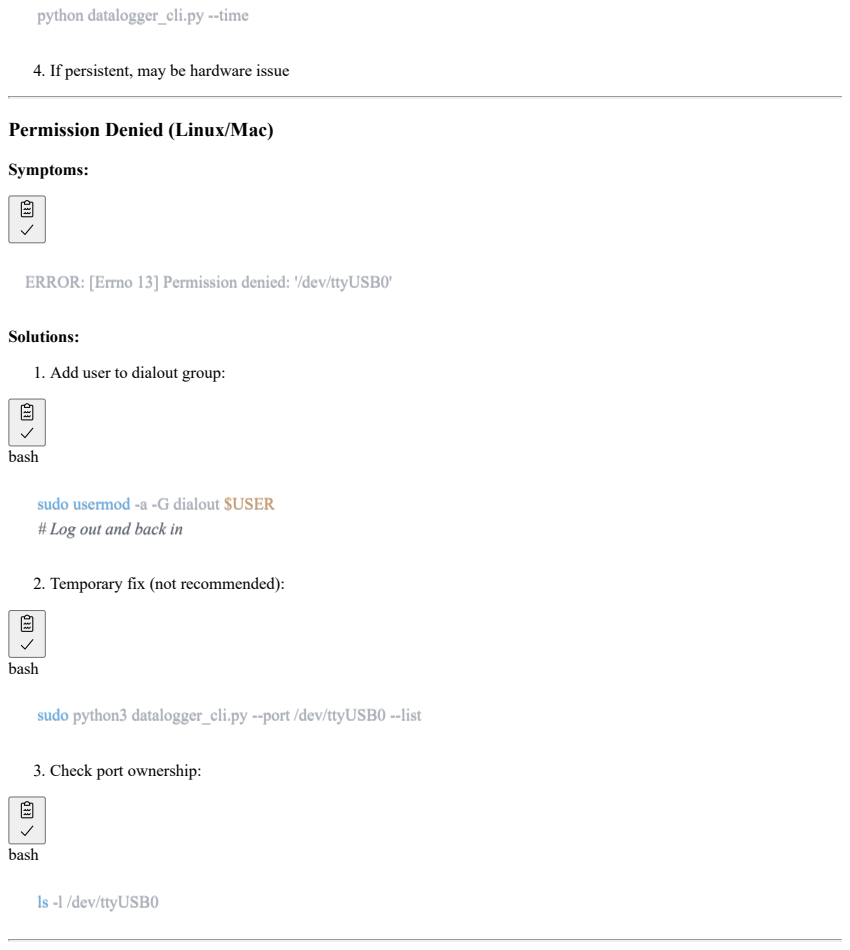
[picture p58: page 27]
Symptoms:; bash; ls -l /dev/ttyUSB0

python datalogger_cli.py --time

4. If persistent, may be hardware issue

Permission Denied (Linux/Mac)

ERROR: [Errno 13] Permission denied: '/dev/ttyUSB0'

Solutions:
1. Add user to dialout group:

sudo usermod -a -G dialout $USER
# Log out and back in

2. Temporary fix (not recommended):

sudo python3 datalogger_cli.py --port /dev/ttyUSB0 --list

3. Check port ownership:

## Quick Reference Card

Essential Commands

bash

# Connection

--port COM19 | # Specify port
--discover | # Auto-find device (default)
--reset | # Reset before connecting

# Data

--list | # Show available logs
--date 2025-10-07 | # Download specific date
--out ./file.csv | # Custom output path

# RTC

--time | # Show current time
--settime now | # Set to PC time

# Sensors

--sense | # Temp, humidity, battery
--vbat | # Battery voltage only

# Config

--interval | # Show log interval
--setinterval 300 | # Set to 5 minutes

# LED

--heartbeat | # Show LED status
--heartbeat-on | # Enable LED
--setheartbeat 10 | # Set 10 sec period

# Storage

--flash-free | # Show storage space
--delete 2025-10-01 | # Delete date logs
--format 246810 | # Format storage (DANGER!)

# System

--reboot | # Restart device

Common Workflows

Initial Setup:

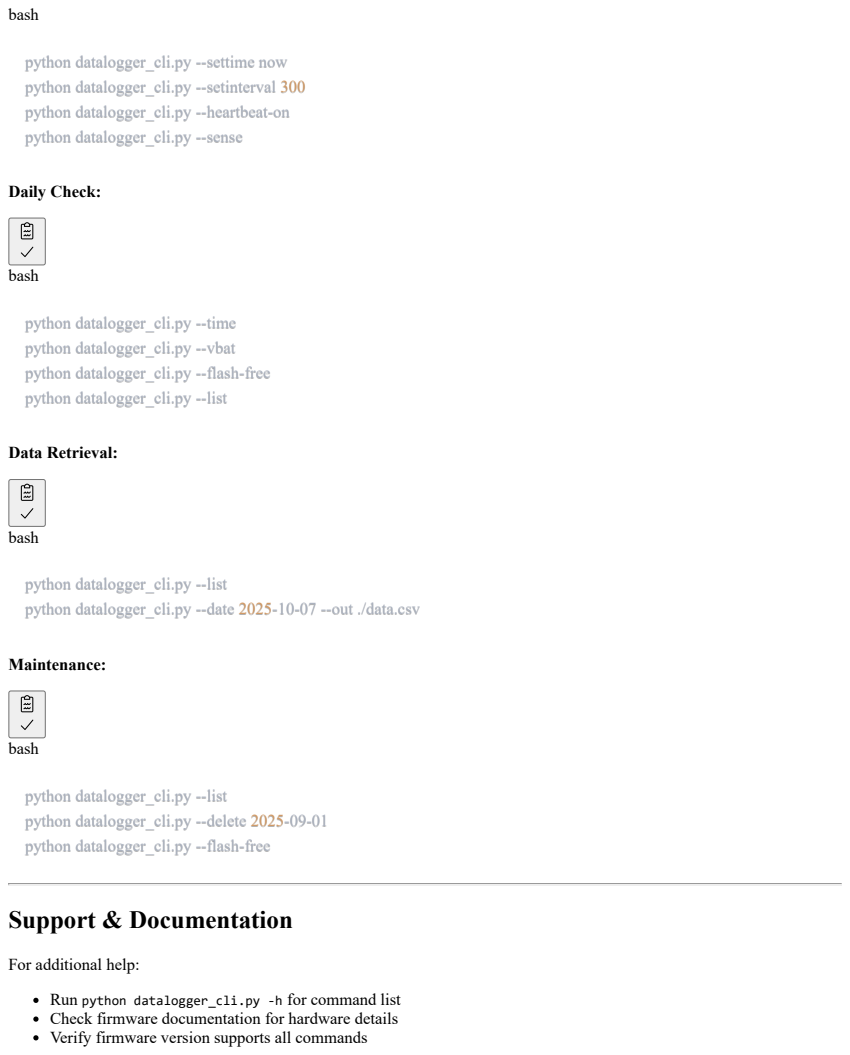
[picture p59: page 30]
bash; Daily Check:; Data Retrieval:; Maintenance:; Support & Documentation

python datalogger_cli.py --settime now
python datalogger_cli.py --setinterval 300
python datalogger_cli.py --heartbeat-on
python datalogger_cli.py --sense

python datalogger_cli.py --time
python datalogger_cli.py --vbat
python datalogger_cli.py --flash-free
python datalogger_cli.py --list

python datalogger_cli.py --date 2025-10-07 --out ./data.csv

python datalogger_cli.py --delete 2025-09-01

For additional help:

Run python datalogger_cli.py -h for command list
Check firmware documentation for hardware details
Verify firmware version supports all commands

Contact technical support for hardware issues

Document Version: 1.0
Last Updated: October 2025
Compatible Firmware: v1.x with all serial commands

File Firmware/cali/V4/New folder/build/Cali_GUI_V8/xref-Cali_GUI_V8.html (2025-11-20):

# modulegraph cross reference for Cali_GUI_V8.py, pyi_rth__tkinter.py, pyi_rth_inspect.py

Cali_GUI_V8.py Script

imports: _collections_abc • _weakrefset • abc • codecs • collections • collections.abc • copyreg • csv • datetime • encodings • encodings.aliases • encodings.ascii • encodings.base64_codec • encodings.big5 • encodings.big5hkscs • encodings.bz2_codec • encodings.charmap • encodings.cp037 • encodings.cp1006 • encodings.cp1026 • encodings.cp1125 • encodings.cp1140 • encodings.cp1250 • encodings.cp1251 • encodings.cp1252 • encodings.cp1253 • encodings.cp1254 • encodings.cp1255 • encodings.cp1256 • encodings.cp1257 • encodings.cp1258 • encodings.cp273 • encodings.cp424 • encodings.cp437 • encodings.cp500 • encodings.cp720 • encodings.cp737 • encodings.cp775 • encodings.cp850 • encodings.cp852 • encodings.cp855 • encodings.cp856 • encodings.cp857 • encodings.cp858 • encodings.cp860 • encodings.cp861 • encodings.cp862 • encodings.cp863 • encodings.cp864 • encodings.cp865 • encodings.cp866 • encodings.cp869 • encodings.cp874 • encodings.cp875 • encodings.cp932 • encodings.cp949 • encodings.cp950 • encodings.euc_jis_2004 • encodings.euc_jisx0213 • encodings.euc_jp • encodings.euc_kr • encodings.gb18030 • encodings.gb2312 • encodings.gbk • encodings.hex_codec • encodings.hp_roman8 • encodings.hz • encodings.idna • encodings.iso2022_jp • encodings.iso2022_jp_1 • encodings.iso2022_jp_2 • encodings.iso2022_jp_2004 • encodings.iso2022_jp_3 • encodings.iso2022_jp_ext • encodings.iso2022_kr • encodings.iso8859_1 • encodings.iso8859_10 • encodings.iso8859_11 • encodings.iso8859_13 • encodings.iso8859_14 • encodings.iso8859_15 • encodings.iso8859_16 • encodings.iso8859_2 • encodings.iso8859_3 • encodings.iso8859_4 • encodings.iso8859_5 • encodings.iso8859_6 • encodings.iso8859_7 • encodings.iso8859_8 • encodings.iso8859_9 • encodings.johab • encodings.koi8_r • encodings.koi8_t • encodings.koi8_u • encodings.kz1048 • encodings.latin_1 • encodings.mac_arabic • encodings.mac_croatian • encodings.mac_cyrillic • encodings.mac_farsi • encodings.mac_greek • encodings.mac_iceland • encodings.mac_latin2 • encodings.mac_roman • encodings.mac_romanian • encodings.mac_turkish • encodings.mbcs • encodings.oem • encodings.palmos • encodings.ptcp154 • encodings.punycode • encodings.quopri_codec • encodings.raw_unicode_escape • encodings.rot_13 • encodings.shift_jis • encodings.shift_jis_2004 • encodings.shift_jisx0213 • encodings.tis_620 • encodings.undefined • encodings.unicode_escape • encodings.utf_16 • encodings.utf_16_be • encodings.utf_16_le • encodings.utf_32 • encodings.utf_32_be • encodings.utf_32_le • encodings.utf_7 • encodings.utf_8 • encodings.utf_8_sig • encodings.uu_codec • encodings.zlib_codec • enum • functools • genericpath • heapq • io • keyword • linecache • locale • ntpath • operator • os • posixpath • pyi_rth__tkinter.py • pyi_rth_inspect.py • queue • re • re._casefix • re._compiler • re._constants • re._parser • reprlib • serial • serial.tools.list_ports • sre_compile • sre_constants • sre_parse • stat • threading • time • tkinter • tkinter.messagebox • tkinter.ttk • traceback • types • warnings • weakref

pyi_rth__tkinter.py Script

imports: os • sys

imported by: Cali_GUI_V8.py

pyi_rth_inspect.py Script

imports: inspect • os • sys • zipfile

imported by: Cali_GUI_V8.py

'System.IO' MissingModule

imported by: serial.serialcli

'org.python' MissingModule

imported by: copy

System MissingModule

imported by: serial.serialcli

__future__ SourceModule

imported by: serial • serial.serialcli • serial.serialjava • serial.serialposix • serial.serialutil • serial.serialwin32 • serial.tools.list_ports • serial.tools.list_ports_common • serial.tools.list_ports_linux • serial.tools.list_ports_osx • serial.tools.list_ports_posix • serial.tools.list_ports_windows • serial.win32

_abc (builtin module)

imported by: abc

_ast (builtin module)

imported by: ast

_bisect (builtin module)

imported by: bisect

_blake2 (builtin module)

imported by: hashlib

_bz2 C:\Users\ashan\AppData\Local\Programs\Python\Python311\DLLs\_bz2.pyd

imported by: bz2

_codecs (builtin module)

imported by: codecs

_codecs_cn (builtin module)

imported by: encodings.gb18030 • encodings.gb2312 • encodings.gbk • encodings.hz

_codecs_hk (builtin module)

imported by: encodings.big5hkscs

_codecs_iso2022 (builtin module)

imported by: encodings.iso2022_jp • encodings.iso2022_jp_1 • encodings.iso2022_jp_2 • encodings.iso2022_jp_2004 • encodings.iso2022_jp_3 • encodings.iso2022_jp_ext • encodings.iso2022_kr

_codecs_jp (builtin module)

imported by: encodings.cp932 • encodings.euc_jis_2004 • encodings.euc_jisx0213 • encodings.euc_jp • encodings.shift_jis • encodings.shift_jis_2004 • encodings.shift_jisx0213

_codecs_kr (builtin module)

imported by: encodings.cp949 • encodings.euc_kr • encodings.johab

_codecs_tw (builtin module)

imported by: encodings.big5 • encodings.cp950

_collections (builtin module)

imported by: collections • threading

_collections_abc SourceModule

imports: abc • sys

imported by: Cali_GUI_V8.py • collections • collections.abc • contextlib • locale • os • pathlib • random • types • weakref

_compat_pickle SourceModule

imported by: _pickle • pickle

_compression SourceModule

imports: io • sys

imported by: bz2 • gzip • lzma

_contextvars (builtin module)

imported by: contextvars

_csv (builtin module)

imported by: csv

_ctypes C:\Users\ashan\AppData\Local\Programs\Python\Python311\DLLs\_ctypes.pyd

imported by: ctypes

_datetime (builtin module)

imports: _strptime • time

imported by: datetime

_decimal C:\Users\ashan\AppData\Local\Programs\Python\Python311\DLLs\_decimal.pyd

imported by: decimal

_frozen_importlib ExcludedModule

imported by: importlib • importlib.abc

_frozen_importlib_external MissingModule

imported by: importlib • importlib._bootstrap • importlib.abc

_functools (builtin module)

imported by: functools

_hashlib C:\Users\ashan\AppData\Local\Programs\Python\Python311\DLLs\_hashlib.pyd

imported by: hashlib

_heapq (builtin module)

imported by: heapq

_imp (builtin module)

imported by: importlib • importlib._bootstrap_external • importlib.util

_io (builtin module)

imported by: importlib._bootstrap_external • io

_locale (builtin module)

imported by: locale

_lzma C:\Users\ashan\AppData\Local\Programs\Python\Python311\DLLs\_lzma.pyd

imported by: lzma

_md5 (builtin module)

imported by: hashlib

_multibytecodec (builtin module)

imported by: encodings.big5 • encodings.big5hkscs • encodings.cp932 • encodings.cp949 • encodings.cp950 • encodings.euc_jis_2004 • encodings.euc_jisx0213 • encodings.euc_jp • encodings.euc_kr • encodings.gb18030 • encodings.gb2312 • encodings.gbk • encodings.hz • encodings.iso2022_jp • encodings.iso2022_jp_1 • encodings.iso2022_jp_2 • encodings.iso2022_jp_2004 • encodings.iso2022_jp_3 • encodings.iso2022_jp_ext • encodings.iso2022_kr • encodings.johab • encodings.shift_jis • encodings.shift_jis_2004 • encodings.shift_jisx0213

_opcode (builtin module)

imported by: opcode

_operator (builtin module)

imported by: operator

_pickle (builtin module)

imports: _compat_pickle • codecs • copyreg

imported by: pickle

_posixsubprocess MissingModule

imports: gc

imported by: subprocess

_py_abc SourceModule

imports: _weakrefset

imported by: abc

_pydecimal SourceModule

imports: collections • contextvars • itertools • locale • math • numbers • re • sys

imported by: decimal

_queue C:\Users\ashan\AppData\Local\Programs\Python\Python311\DLLs\_queue.pyd

imported by: queue

_random (builtin module)

imported by: random

_sha1 (builtin module)

imported by: hashlib

_sha256 (builtin module)

imported by: hashlib

_sha3 (builtin module)

imported by: hashlib

_sha512 (builtin module)

imported by: hashlib • random

_signal (builtin module)

imported by: signal

_socket C:\Users\ashan\AppData\Local\Programs\Python\Python311\DLLs\_socket.pyd

imported by: socket

_sre (builtin module)

imports: copy • re

imported by: re._compiler • re._constants

_stat (builtin module)

imported by: stat

_statistics (builtin module)

imported by: statistics

_string (builtin module)

imported by: string

_strptime SourceModule

imports: _thread • calendar • datetime • locale • re • time

imported by: _datetime • datetime • time

_struct (builtin module)

imported by: struct

_thread (builtin module)

imported by: _strptime • dataclasses • functools • reprlib • tempfile • threading

_threading_local SourceModule

imports: contextlib • threading • weakref

imported by: threading

_tkinter C:\Users\ashan\AppData\Local\Programs\Python\Python311\DLLs\_tkinter.pyd

imported by: tkinter

_tokenize (builtin module)

imported by: tokenize

_tracemalloc (builtin module)

imported by: tracemalloc

_typing (builtin module)

imported by: typing

_warnings (builtin module)

imported by: importlib._bootstrap_external • warnings

_weakref (builtin module)

imported by: _weakrefset • collections • weakref

_weakrefset SourceModule

imports: _weakref • types

imported by: Cali_GUI_V8.py • _py_abc • threading • weakref

_winapi (builtin module)

imported by: encodings • ntpath • subprocess

abc SourceModule

imports: _abc • _py_abc

imported by: Cali_GUI_V8.py • _collections_abc • contextlib • dataclasses • email._policybase • functools • importlib._abc • importlib.abc • importlib.metadata • importlib.resources.abc • inspect • io • numbers • os • selectors • typing

argparse SourceModule

imports: copy • gettext • os • re • shutil • sys • textwrap • warnings

imported by: ast • calendar • dis • gzip • inspect • py_compile • serial.tools.list_ports • tarfile • tokenize • zipfile

array (builtin module)

imported by: serial.serialposix • serial.serialutil • socket

ast SourceModule

imports: _ast • argparse • collections • contextlib • enum • inspect • sys • warnings

imported by: inspect • traceback

atexit (builtin module)

imported by: logging • weakref

base64 SourceModule

imports: binascii • getopt • re • struct • sys

imported by: email._encoded_words • email.base64mime • email.encoders • encodings.base64_codec

binascii (builtin module)

imported by: base64 • email._encoded_words • email.base64mime • email.contentmanager • email.header • email.message • encodings.hex_codec • encodings.uu_codec • quopri • zipfile

bisect SourceModule

imports: _bisect

imported by: random • statistics

builtins (builtin module)

imported by: bz2 • codecs • dataclasses • enum • gettext • gzip • inspect • locale • lzma • operator • reprlib • subprocess • tarfile • tokenize • warnings

bz2 SourceModule

imports: _bz2 • _compression • builtins • io • os

imported by: encodings.bz2_codec • shutil • tarfile • zipfile

calendar SourceModule

imports: argparse • datetime • itertools • locale • sys

imported by: _strptime • email._parseaddr

codecs SourceModule

imports: _codecs • builtins • encodings • sys

imported by: Cali_GUI_V8.py • _pickle • encodings • encodings.ascii • encodings.base64_codec • encodings.big5 • encodings.big5hkscs • encodings.bz2_codec • encodings.charmap • encodings.cp037 • encodings.cp1006 • encodings.cp1026 • encodings.cp1125 • encodings.cp1140 • encodings.cp1250 • encodings.cp1251 • encodings.cp1252 • encodings.cp1253 • encodings.cp1254 • encodings.cp1255 • encodings.cp1256 • encodings.cp1257 • encodings.cp1258 • encodings.cp273 • encodings.cp424 • encodings.cp437 • encodings.cp500 • encodings.cp720 • encodings.cp737 • encodings.cp775 • encodings.cp850 • encodings.cp852 • encodings.cp855 • encodings.cp856 • encodings.cp857 • encodings.cp858 • encodings.cp860 • encodings.cp861 • encodings.cp862 • encodings.cp863 • encodings.cp864 • encodings.cp865 • encodings.cp866 • encodings.cp869 • encodings.cp874 • encodings.cp875 • encodings.cp932 • encodings.cp949 • encodings.cp950 • encodings.euc_jis_2004 • encodings.euc_jisx0213 • encodings.euc_jp • encodings.euc_kr • encodings.gb18030 • encodings.gb2312 • encodings.gbk • encodings.hex_codec • encodings.hp_roman8 • encodings.hz • encodings.idna • encodings.iso2022_jp • encodings.iso2022_jp_1 • encodings.iso2022_jp_2 • encodings.iso2022_jp_2004 • encodings.iso2022_jp_3 • encodings.iso2022_jp_ext • encodings.iso2022_kr • encodings.iso8859_1 • encodings.iso8859_10 • encodings.iso8859_11 • encodings.iso8859_13 • encodings.iso8859_14 • encodings.iso8859_15 • encodings.iso8859_16 • encodings.iso8859_2 • encodings.iso8859_3 • encodings.iso8859_4 • encodings.iso8859_5 • encodings.iso8859_6 • encodings.iso8859_7 • encodings.iso8859_8 • encodings.iso8859_9 • encodings.johab • encodings.koi8_r • encodings.koi8_t • encodings.koi8_u • encodings.kz1048 • encodings.latin_1 • encodings.mac_arabic • encodings.mac_croatian • encodings.mac_cyrillic • encodings.mac_farsi • encodings.mac_greek • encodings.mac_iceland • encodings.mac_latin2 • encodings.mac_roman • encodings.mac_romanian • encodings.mac_turkish • encodings.mbcs • encodings.oem • encodings.palmos • encodings.ptcp154 • encodings.punycode • encodings.quopri_codec • encodings.raw_unicode_escape • encodings.rot_13 • encodings.shift_jis • encodings.shift_jis_2004 • encodings.shift_jisx0213 • encodings.tis_620 • encodings.undefined • encodings.unicode_escape • encodings.utf_16 • encodings.utf_16_be • encodings.utf_16_le • encodings.utf_32 • encodings.utf_32_be • encodings.utf_32_le • encodings.utf_7 • encodings.utf_8 • encodings.utf_8_sig • encodings.uu_codec • encodings.zlib_codec • pickle • tokenize

collections Package

imports: _collections • _collections_abc • _weakref • copy • heapq • itertools • keyword • operator • reprlib • sys

imported by: Cali_GUI_V8.py • _pydecimal • ast • collections.abc • contextlib • dis • email.feedparser • functools • importlib.metadata • importlib.metadata._collections • importlib.resources.readers • inspect • pprint • queue • selectors • shutil • statistics • string • threading • tkinter • tokenize • typing • urllib.parse

collections.abc SourceModule

imports: _collections_abc • collections

imported by: Cali_GUI_V8.py • inspect • logging • selectors • traceback • tracemalloc • typing

contextlib SourceModule

imports: _collections_abc • abc • collections • functools • os • sys • types

imported by: _threading_local • ast • glob • importlib.metadata • importlib.resources._adapters • importlib.resources._common • importlib.util • subprocess • traceback • typing • zipfile

contextvars SourceModule

imports: _contextvars

imported by: _pydecimal

copy SourceModule

imports: 'org.python' • copyreg • types • weakref

imported by: _sre • argparse • collections • dataclasses • email.generator • gettext • tarfile • weakref

copyreg SourceModule

imports: functools • operator

imported by: Cali_GUI_V8.py • _pickle • copy • pickle • re

csv SourceModule

imports: _csv • io • re

imported by: Cali_GUI_V8.py • importlib.metadata

ctypes Package

imports: _ctypes • ctypes._endian • nt • os • struct • sys • types

imported by: ctypes._endian • ctypes.wintypes • serial.serialwin32 • serial.tools.list_ports_osx • serial.tools.list_ports_windows • serial.win32

ctypes._endian SourceModule

imports: ctypes • sys

imported by: ctypes

ctypes.wintypes SourceModule

imports: ctypes

imported by: serial.tools.list_ports_windows • serial.win32

dataclasses SourceModule

imports: _thread • abc • builtins • copy • functools • inspect • itertools • keyword • re • sys • types

imported by: pprint

datetime SourceModule

imports: _datetime • _strptime • math • operator • sys • time

imported by: Cali_GUI_V8.py • _strptime • calendar • email.utils

decimal SourceModule

imports: _decimal • _pydecimal

imported by: fractions • statistics

dis SourceModule

imports: argparse • collections • io • opcode • sys • types

imported by: inspect

email Package

imports: email._header_value_parser • email.charset • email.errors • email.header • email.parser

imported by: email._encoded_words • email._header_value_parser • email._parseaddr • email._policybase • email.base64mime • email.charset • email.contentmanager • email.encoders • email.errors • email.feedparser • email.generator • email.header • email.headerregistry • email.iterators • email.message • email.parser • email.policy • email.quoprimime • email.utils • importlib.metadata

email._encoded_words SourceModule

imports: base64 • binascii • email • email.errors • functools • re • string

imported by: email._header_value_parser • email.message

email._header_value_parser SourceModule

imports: email • email._encoded_words • email.errors • email.utils • operator • re • string • sys • urllib

imported by: email • email.headerregistry

email._parseaddr SourceModule

imports: calendar • email • time

imported by: email.utils

email._policybase SourceModule

imports: abc • email • email.charset • email.header • email.utils

imported by: email.feedparser • email.message • email.parser • email.policy

email.base64mime SourceModule

imports: base64 • binascii • email

imported by: email.charset • email.header

email.charset SourceModule

imports: email • email.base64mime • email.encoders • email.errors • email.quoprimime • functools

imported by: email • email._policybase • email.contentmanager • email.header • email.message • email.utils

email.contentmanager SourceModule

imports: binascii • email • email.charset • email.errors • email.message • email.quoprimime

imported by: email.policy

email.encoders SourceModule

imports: base64 • email • quopri

imported by: email.charset

email.errors SourceModule

imports: email

imported by: email • email._encoded_words • email._header_value_parser • email.charset • email.contentmanager • email.feedparser • email.header • email.headerregistry • email.message

email.feedparser SourceModule

imports: collections • email • email._policybase • email.errors • email.message • io • re

imported by: email.parser

email.generator SourceModule

imports: copy • email • email.utils • io • random • re • sys • time

imported by: email.message

email.header SourceModule

imports: binascii • email • email.base64mime • email.charset • email.errors • email.quoprimime • re

imported by: email • email._policybase

email.headerregistry SourceModule

imports: email • email._header_value_parser • email.errors • email.utils • types

imported by: email.policy

email.iterators SourceModule

imports: email • io • sys

imported by: email.message

email.message SourceModule

imports: binascii • email • email._encoded_words • email._policybase • email.charset • email.errors • email.generator • email.iterators • email.policy • email.utils • io • quopri • re

imported by: email.contentmanager • email.feedparser • email.policy • importlib.metadata._adapters

email.parser SourceModule

imports: email • email._policybase • email.feedparser • io

imported by: email

email.policy SourceModule

imports: email • email._policybase • email.contentmanager • email.headerregistry • email.message • email.utils • re • sys

imported by: email.message

email.quoprimime SourceModule

imports: email • re • string

imported by: email.charset • email.contentmanager • email.header

email.utils SourceModule

imports: datetime • email • email._parseaddr • email.charset • os • random • re • socket • time • urllib.parse

imported by: email._header_value_parser • email._policybase • email.generator • email.headerregistry • email.message • email.policy

encodings Package

imports: _winapi • codecs • encodings • encodings.aliases • encodings.ascii • encodings.base64_codec • encodings.big5 • encodings.big5hkscs • encodings.bz2_codec • encodings.charmap • encodings.cp037 • encodings.cp1006 • encodings.cp1026 • encodings.cp1125 • encodings.cp1140 • encodings.cp1250 • encodings.cp1251 • encodings.cp1252 • encodings.cp1253 • encodings.cp1254 • encodings.cp1255 • encodings.cp1256 • encodings.cp1257 • encodings.cp1258 • encodings.cp273 • encodings.cp424 • encodings.cp437 • encodings.cp500 • encodings.cp720 • encodings.cp737 • encodings.cp775 • encodings.cp850 • encodings.cp852 • encodings.cp855 • encodings.cp856 • encodings.cp857 • encodings.cp858 • encodings.cp860 • encodings.cp861 • encodings.cp862 • encodings.cp863 • encodings.cp864 • encodings.cp865 • encodings.cp866 • encodings.cp869 • encodings.cp874 • encodings.cp875 • encodings.cp932 • encodings.cp949 • encodings.cp950 • encodings.euc_jis_2004 • encodings.euc_jisx0213 • encodings.euc_jp • encodings.euc_kr • encodings.gb18030 • encodings.gb2312 • encodings.gbk • encodings.hex_codec • encodings.hp_roman8 • encodings.hz • encodings.idna • encodings.iso2022_jp • encodings.iso2022_jp_1 • encodings.iso2022_jp_2 • encodings.iso2022_jp_2004 • encodings.iso2022_jp_3 • encodings.iso2022_jp_ext • encodings.iso2022_kr • encodings.iso8859_1 • encodings.iso8859_10 • encodings.iso8859_11 • encodings.iso8859_13 • encodings.iso8859_14 • encodings.iso8859_15 • encodings.iso8859_16 • encodings.iso8859_2 • encodings.iso8859_3 • encodings.iso8859_4 • encodings.iso8859_5 • encodings.iso8859_6 • encodings.iso8859_7 • encodings.iso8859_8 • encodings.iso8859_9 • encodings.johab • encodings.koi8_r • encodings.koi8_t • encodings.koi8_u • encodings.kz1048 • encodings.latin_1 • encodings.mac_arabic • encodings.mac_croatian • encodings.mac_cyrillic • encodings.mac_farsi • encodings.mac_greek • encodings.mac_iceland • encodings.mac_latin2 • encodings.mac_roman • encodings.mac_romanian • encodings.mac_turkish • encodings.mbcs • encodings.oem • encodings.palmos • encodings.ptcp154 • encodings.punycode • encodings.quopri_codec • encodings.raw_unicode_escape • encodings.rot_13 • encodings.shift_jis • encodings.shift_jis_2004 • encodings.shift_jisx0213 • encodings.tis_620 • encodings.undefined • encodings.unicode_escape • encodings.utf_16 • encodings.utf_16_be • encodings.utf_16_le • encodings.utf_32 • encodings.utf_32_be • encodings.utf_32_le • encodings.utf_7 • encodings.utf_8 • encodings.utf_8_sig • encodings.uu_codec • encodings.zlib_codec • sys

imported by: Cali_GUI_V8.py • codecs • encodings • encodings.aliases • encodings.ascii • encodings.base64_codec • encodings.big5 • encodings.big5hkscs • encodings.bz2_codec • encodings.charmap • encodings.cp037 • encodings.cp1006 • encodings.cp1026 • encodings.cp1125 • encodings.cp1140 • encodings.cp1250 • encodings.cp1251 • encodings.cp1252 • encodings.cp1253 • encodings.cp1254 • encodings.cp1255 • encodings.cp1256 • encodings.cp1257 • encodings.cp1258 • encodings.cp273 • encodings.cp424 • encodings.cp437 • encodings.cp500 • encodings.cp720 • encodings.cp737 • encodings.cp775 • encodings.cp850 • encodings.cp852 • encodings.cp855 • encodings.cp856 • encodings.cp857 • encodings.cp858 • encodings.cp860 • encodings.cp861 • encodings.cp862 • encodings.cp863 • encodings.cp864 • encodings.cp865 • encodings.cp866 • encodings.cp869 • encodings.cp874 • encodings.cp875 • encodings.cp932 • encodings.cp949 • encodings.cp950 • encodings.euc_jis_2004 • encodings.euc_jisx0213 • encodings.euc_jp • encodings.euc_kr • encodings.gb18030 • encodings.gb2312 • encodings.gbk • encodings.hex_codec • encodings.hp_roman8 • encodings.hz • encodings.idna • encodings.iso2022_jp • encodings.iso2022_jp_1 • encodings.iso2022_jp_2 • encodings.iso2022_jp_2004 • encodings.iso2022_jp_3 • encodings.iso2022_jp_ext • encodings.iso2022_kr • encodings.iso8859_1 • encodings.iso8859_10 • encodings.iso8859_11 • encodings.iso8859_13 • encodings.iso8859_14 • encodings.iso8859_15 • encodings.iso8859_16 • encodings.iso8859_2 • encodings.iso8859_3 • encodings.iso8859_4 • encodings.iso8859_5 • encodings.iso8859_6 • encodings.iso8859_7 • encodings.iso8859_8 • encodings.iso8859_9 • encodings.johab • encodings.koi8_r • encodings.koi8_t • encodings.koi8_u • encodings.kz1048 • encodings.latin_1 • encodings.mac_arabic • encodings.mac_croatian • encodings.mac_cyrillic • encodings.mac_farsi • encodings.mac_greek • encodings.mac_iceland • encodings.mac_latin2 • encodings.mac_roman • encodings.mac_romanian • encodings.mac_turkish • encodings.mbcs • encodings.oem • encodings.palmos • encodings.ptcp154 • encodings.punycode • encodings.quopri_codec • encodings.raw_unicode_escape • encodings.rot_13 • encodings.shift_jis • encodings.shift_jis_2004 • encodings.shift_jisx0213 • encodings.tis_620 • encodings.undefined • encodings.unicode_escape • encodings.utf_16 • encodings.utf_16_be • encodings.utf_16_le • encodings.utf_32 • encodings.utf_32_be • encodings.utf_32_le • encodings.utf_7 • encodings.utf_8 • encodings.utf_8_sig • encodings.uu_codec • encodings.zlib_codec • locale

encodings.aliases SourceModule

imports: encodings

imported by: Cali_GUI_V8.py • encodings • locale

encodings.ascii SourceModule

imports: codecs • encodings

imported by: Cali_GUI_V8.py • encodings

encodings.base64_codec SourceModule

imports: base64 • codecs • encodings

imported by: Cali_GUI_V8.py • encodings

encodings.big5 SourceModule

imports: _codecs_tw • _multibytecodec • codecs • encodings

imported by: Cali_GUI_V8.py • encodings

encodings.big5hkscs SourceModule

imports: _codecs_hk • _multibytecodec • codecs • encodings

imported by: Cali_GUI_V8.py • encodings

encodings.bz2_codec SourceModule

imports: bz2 • codecs • encodings

imported by: Cali_GUI_V8.py • encodings

encodings.charmap SourceModule

imports: codecs • encodings

imported by: Cali_GUI_V8.py • encodings

encodings.cp037 SourceModule

imports: codecs • encodings

imported by: Cali_GUI_V8.py • encodings

encodings.cp1006 SourceModule

imports: codecs • encodings

imported by: Cali_GUI_V8.py • encodings

encodings.cp1026 SourceModule

imports: codecs • encodings

imported by: Cali_GUI_V8.py • encodings

encodings.cp1125 SourceModule

imports: codecs • encodings

imported by: Cali_GUI_V8.py • encodings

encodings.cp1140 SourceModule

imports: codecs • encodings

imported by: Cali_GUI_V8.py • encodings

encodings.cp1250 SourceModule

imports: codecs • encodings

imported by: Cali_GUI_V8.py • encodings

encodings.cp1251 SourceModule

imports: codecs • encodings

imported by: Cali_GUI_V8.py • encodings

encodings.cp1252 SourceModule

imports: codecs • encodings

imported by: Cali_GUI_V8.py • encodings

encodings.cp1253 SourceModule

imports: codecs • encodings

imported by: Cali_GUI_V8.py • encodings

encodings.cp1254 SourceModule

imports: codecs • encodings

imported by: Cali_GUI_V8.py • encodings

encodings.cp1255 SourceModule

imports: codecs • encodings

imported by: Cali_GUI_V8.py • encodings

encodings.cp1256 SourceModule

imports: codecs • encodings

imported by: Cali_GUI_V8.py • encodings

encodings.cp1257 SourceModule

imports: codecs • encodings

imported by: Cali_GUI_V8.py • encodings

encodings.cp1258 SourceModule

imports: codecs • encodings

imported by: Cali_GUI_V8.py • encodings

encodings.cp273 SourceModule

imports: codecs • encodings

imported by: Cali_GUI_V8.py • encodings

encodings.cp424 SourceModule

imports: codecs • encodings

imported by: Cali_GUI_V8.py • encodings

encodings.cp437 SourceModule

imports: codecs • encodings

imported by: Cali_GUI_V8.py • encodings

encodings.cp500 SourceModule

imports: codecs • encodings

imported by: Cali_GUI_V8.py • encodings

encodings.cp720 SourceModule

imports: codecs • encodings

imported by: Cali_GUI_V8.py • encodings

encodings.cp737 SourceModule

imports: codecs • encodings

imported by: Cali_GUI_V8.py • encodings

encodings.cp775 SourceModule

imports: codecs • encodings

imported by: Cali_GUI_V8.py • encodings

encodings.cp850 SourceModule

imports: codecs • encodings

imported by: Cali_GUI_V8.py • encodings

encodings.cp852 SourceModule

imports: codecs • encodings

imported by: Cali_GUI_V8.py • encodings

encodings.cp855 SourceModule

imports: codecs • encodings

imported by: Cali_GUI_V8.py • encodings

encodings.cp856 SourceModule

imports: codecs • encodings

imported by: Cali_GUI_V8.py • encodings

encodings.cp857 SourceModule

imports: codecs • encodings

imported by: Cali_GUI_V8.py • encodings

encodings.cp858 SourceModule

imports: codecs • encodings

imported by: Cali_GUI_V8.py • encodings

encodings.cp860 SourceModule

imports: codecs • encodings

imported by: Cali_GUI_V8.py • encodings

encodings.cp861 SourceModule

imports: codecs • encodings

imported by: Cali_GUI_V8.py • encodings

encodings.cp862 SourceModule

imports: codecs • encodings

imported by: Cali_GUI_V8.py • encodings

encodings.cp863 SourceModule

imports: codecs • encodings

imported by: Cali_GUI_V8.py • encodings

encodings.cp864 SourceModule

imports: codecs • encodings

imported by: Cali_GUI_V8.py • encodings

encodings.cp865 SourceModule

imports: codecs • encodings

imported by: Cali_GUI_V8.py • encodings

encodings.cp866 SourceModule

imports: codecs • encodings

imported by: Cali_GUI_V8.py • encodings

encodings.cp869 SourceModule

imports: codecs • encodings

imported by: Cali_GUI_V8.py • encodings

encodings.cp874 SourceModule

imports: codecs • encodings

imported by: Cali_GUI_V8.py • encodings

encodings.cp875 SourceModule

imports: codecs • encodings

imported by: Cali_GUI_V8.py • encodings

encodings.cp932 SourceModule

imports: _codecs_jp • _multibytecodec • codecs • encodings

imported by: Cali_GUI_V8.py • encodings

encodings.cp949 SourceModule

imports: _codecs_kr • _multibytecodec • codecs • encodings

imported by: Cali_GUI_V8.py • encodings

encodings.cp950 SourceModule

imports: _codecs_tw • _multibytecodec • codecs • encodings

imported by: Cali_GUI_V8.py • encodings

encodings.euc_jis_2004 SourceModule

imports: _codecs_jp • _multibytecodec • codecs • encodings

imported by: Cali_GUI_V8.py • encodings

encodings.euc_jisx0213 SourceModule

imports: _codecs_jp • _multibytecodec • codecs • encodings

imported by: Cali_GUI_V8.py • encodings

encodings.euc_jp SourceModule

imports: _codecs_jp • _multibytecodec • codecs • encodings

imported by: Cali_GUI_V8.py • encodings

encodings.euc_kr SourceModule

imports: _codecs_kr • _multibytecodec • codecs • encodings

imported by: Cali_GUI_V8.py • encodings

encodings.gb18030 SourceModule

imports: _codecs_cn • _multibytecodec • codecs • encodings

imported by: Cali_GUI_V8.py • encodings

encodings.gb2312 SourceModule

imports: _codecs_cn • _multibytecodec • codecs • encodings

imported by: Cali_GUI_V8.py • encodings

encodings.gbk SourceModule

imports: _codecs_cn • _multibytecodec • codecs • encodings

imported by: Cali_GUI_V8.py • encodings

encodings.hex_codec SourceModule

imports: binascii • codecs • encodings

imported by: Cali_GUI_V8.py • encodings

encodings.hp_roman8 SourceModule

imports: codecs • encodings

imported by: Cali_GUI_V8.py • encodings

encodings.hz SourceModule

imports: _codecs_cn • _multibytecodec • codecs • encodings

imported by: Cali_GUI_V8.py • encodings

encodings.idna SourceModule

imports: codecs • encodings • re • stringprep • unicodedata

imported by: Cali_GUI_V8.py • encodings

encodings.iso2022_jp SourceModule

imports: _codecs_iso2022 • _multibytecodec • codecs • encodings

imported by: Cali_GUI_V8.py • encodings

encodings.iso2022_jp_1 SourceModule

imports: _codecs_iso2022 • _multibytecodec • codecs • encodings

imported by: Cali_GUI_V8.py • encodings

encodings.iso2022_jp_2 SourceModule

imports: _codecs_iso2022 • _multibytecodec • codecs • encodings

imported by: Cali_GUI_V8.py • encodings

encodings.iso2022_jp_2004 SourceModule

imports: _codecs_iso2022 • _multibytecodec • codecs • encodings

imported by: Cali_GUI_V8.py • encodings

encodings.iso2022_jp_3 SourceModule

imports: _codecs_iso2022 • _multibytecodec • codecs • encodings

imported by: Cali_GUI_V8.py • encodings

encodings.iso2022_jp_ext SourceModule

imports: _codecs_iso2022 • _multibytecodec • codecs • encodings

imported by: Cali_GUI_V8.py • encodings

encodings.iso2022_kr SourceModule

imports: _codecs_iso2022 • _multibytecodec • codecs • encodings

imported by: Cali_GUI_V8.py • encodings

encodings.iso8859_1 SourceModule

imports: codecs • encodings

imported by: Cali_GUI_V8.py • encodings

encodings.iso8859_10 SourceModule

imports: codecs • encodings

imported by: Cali_GUI_V8.py • encodings

encodings.iso8859_11 SourceModule

imports: codecs • encodings

imported by: Cali_GUI_V8.py • encodings

encodings.iso8859_13 SourceModule

imports: codecs • encodings

imported by: Cali_GUI_V8.py • encodings

encodings.iso8859_14 SourceModule

imports: codecs • encodings

imported by: Cali_GUI_V8.py • encodings

encodings.iso8859_15 SourceModule

imports: codecs • encodings

imported by: Cali_GUI_V8.py • encodings

encodings.iso8859_16 SourceModule

imports: codecs • encodings

imported by: Cali_GUI_V8.py • encodings

encodings.iso8859_2 SourceModule

imports: codecs • encodings

imported by: Cali_GUI_V8.py • encodings

encodings.iso8859_3 SourceModule

imports: codecs • encodings

imported by: Cali_GUI_V8.py • encodings

encodings.iso8859_4 SourceModule

imports: codecs • encodings

imported by: Cali_GUI_V8.py • encodings

encodings.iso8859_5 SourceModule

imports: codecs • encodings

imported by: Cali_GUI_V8.py • encodings

encodings.iso8859_6 SourceModule

imports: codecs • encodings

imported by: Cali_GUI_V8.py • encodings

encodings.iso8859_7 SourceModule

imports: codecs • encodings

imported by: Cali_GUI_V8.py • encodings

encodings.iso8859_8 SourceModule

imports: codecs • encodings

imported by: Cali_GUI_V8.py • encodings

encodings.iso8859_9 SourceModule

imports: codecs • encodings

imported by: Cali_GUI_V8.py • encodings

encodings.johab SourceModule

imports: _codecs_kr • _multibytecodec • codecs • encodings

imported by: Cali_GUI_V8.py • encodings

encodings.koi8_r SourceModule

imports: codecs • encodings

imported by: Cali_GUI_V8.py • encodings

encodings.koi8_t SourceModule

imports: codecs • encodings

imported by: Cali_GUI_V8.py • encodings

encodings.koi8_u SourceModule

imports: codecs • encodings

imported by: Cali_GUI_V8.py • encodings

encodings.kz1048 SourceModule

imports: codecs • encodings

imported by: Cali_GUI_V8.py • encodings

encodings.latin_1 SourceModule

imports: codecs • encodings

imported by: Cali_GUI_V8.py • encodings

encodings.mac_arabic SourceModule

imports: codecs • encodings

imported by: Cali_GUI_V8.py • encodings

encodings.mac_croatian SourceModule

imports: codecs • encodings

imported by: Cali_GUI_V8.py • encodings

encodings.mac_cyrillic SourceModule

imports: codecs • encodings

imported by: Cali_GUI_V8.py • encodings

encodings.mac_farsi SourceModule

imports: codecs • encodings

imported by: Cali_GUI_V8.py • encodings

encodings.mac_greek SourceModule

imports: codecs • encodings

imported by: Cali_GUI_V8.py • encodings

encodings.mac_iceland SourceModule

imports: codecs • encodings

imported by: Cali_GUI_V8.py • encodings

encodings.mac_latin2 SourceModule

imports: codecs • encodings

imported by: Cali_GUI_V8.py • encodings

encodings.mac_roman SourceModule

imports: codecs • encodings

imported by: Cali_GUI_V8.py • encodings

encodings.mac_romanian SourceModule

imports: codecs • encodings

imported by: Cali_GUI_V8.py • encodings

encodings.mac_turkish SourceModule

imports: codecs • encodings

imported by: Cali_GUI_V8.py • encodings

encodings.mbcs SourceModule

imports: codecs • encodings

imported by: Cali_GUI_V8.py • encodings

encodings.oem SourceModule

imports: codecs • encodings

imported by: Cali_GUI_V8.py • encodings

encodings.palmos SourceModule

imports: codecs • encodings

imported by: Cali_GUI_V8.py • encodings

encodings.ptcp154 SourceModule

imports: codecs • encodings

imported by: Cali_GUI_V8.py • encodings

encodings.punycode SourceModule

imports: codecs • encodings

imported by: Cali_GUI_V8.py • encodings

encodings.quopri_codec SourceModule

imports: codecs • encodings • io • quopri

imported by: Cali_GUI_V8.py • encodings

encodings.raw_unicode_escape SourceModule

imports: codecs • encodings

imported by: Cali_GUI_V8.py • encodings

encodings.rot_13 SourceModule

imports: codecs • encodings • sys

imported by: Cali_GUI_V8.py • encodings

encodings.shift_jis SourceModule

imports: _codecs_jp • _multibytecodec • codecs • encodings

imported by: Cali_GUI_V8.py • encodings

encodings.shift_jis_2004 SourceModule

imports: _codecs_jp • _multibytecodec • codecs • encodings

imported by: Cali_GUI_V8.py • encodings

encodings.shift_jisx0213 SourceModule

imports: _codecs_jp • _multibytecodec • codecs • encodings

imported by: Cali_GUI_V8.py • encodings

encodings.tis_620 SourceModule

imports: codecs • encodings

imported by: Cali_GUI_V8.py • encodings

encodings.undefined SourceModule

imports: codecs • encodings

imported by: Cali_GUI_V8.py • encodings

encodings.unicode_escape SourceModule

imports: codecs • encodings

imported by: Cali_GUI_V8.py • encodings

encodings.utf_16 SourceModule

imports: codecs • encodings • sys

imported by: Cali_GUI_V8.py • encodings

encodings.utf_16_be SourceModule

imports: codecs • encodings

imported by: Cali_GUI_V8.py • encodings

encodings.utf_16_le SourceModule

imports: codecs • encodings

imported by: Cali_GUI_V8.py • encodings

encodings.utf_32 SourceModule

imports: codecs • encodings • sys

imported by: Cali_GUI_V8.py • encodings

encodings.utf_32_be SourceModule

imports: codecs • encodings

imported by: Cali_GUI_V8.py • encodings

encodings.utf_32_le SourceModule

imports: codecs • encodings

imported by: Cali_GUI_V8.py • encodings

encodings.utf_7 SourceModule

imports: codecs • encodings

imported by: Cali_GUI_V8.py • encodings

encodings.utf_8 SourceModule

imports: codecs • encodings

imported by: Cali_GUI_V8.py • encodings

encodings.utf_8_sig SourceModule

imports: codecs • encodings

imported by: Cali_GUI_V8.py • encodings

encodings.uu_codec SourceModule

imports: binascii • codecs • encodings • io

imported by: Cali_GUI_V8.py • encodings

encodings.zlib_codec SourceModule

imports: codecs • encodings • zlib

imported by: Cali_GUI_V8.py • encodings

enum SourceModule

imports: builtins • functools • operator • sys • types • warnings

imported by: Cali_GUI_V8.py • ast • inspect • py_compile • re • signal • socket • tkinter

errno (builtin module)

imported by: gettext • gzip • pathlib • serial.serialposix • shutil • socket • subprocess • tempfile

fcntl MissingModule

imported by: serial.serialposix • subprocess

fnmatch SourceModule

imports: functools • os • posixpath • re

imported by: glob • pathlib • shutil • tracemalloc

fractions SourceModule

imports: decimal • math • numbers • operator • re • sys

imported by: statistics

functools SourceModule

imports: _functools • _thread • abc • collections • reprlib • types • typing • weakref

imported by: Cali_GUI_V8.py • contextlib • copyreg • dataclasses • email._encoded_words • email.charset • enum • fnmatch • importlib.metadata • importlib.metadata._functools • importlib.resources._common • importlib.resources._legacy • importlib.util • inspect • ipaddress • linecache • locale • operator • pathlib • pickle • re • statistics • tempfile • threading • tokenize • tracemalloc • types • typing • urllib.parse

gc (builtin module)

imports: time

imported by: _posixsubprocess • weakref

genericpath SourceModule

imports: os • stat

imported by: Cali_GUI_V8.py • ntpath • posixpath

getopt SourceModule

imports: gettext • os • sys

imported by: base64 • quopri

gettext SourceModule

imports: builtins • copy • errno • locale • operator • os • re • struct • sys • warnings

imported by: argparse • getopt

glob SourceModule

imports: contextlib • fnmatch • itertools • os • re • stat • sys

imported by: serial.tools.list_ports_common • serial.tools.list_ports_linux • serial.tools.list_ports_posix

grp MissingModule

imported by: pathlib • shutil • subprocess • tarfile

gzip SourceModule

imports: _compression • argparse • builtins • errno • io • os • struct • sys • time • warnings • zlib

imported by: tarfile

hashlib SourceModule

imports: _blake2 • _hashlib • _md5 • _sha1 • _sha256 • _sha3 • _sha512 • logging • warnings

imported by: random

heapq SourceModule

imports: _heapq

imported by: Cali_GUI_V8.py • collections • queue

importlib Package

imports: _frozen_importlib • _frozen_importlib_external • _imp • importlib • importlib._bootstrap • importlib._bootstrap_external • sys • warnings

imported by: importlib • importlib._abc • importlib._bootstrap • importlib._bootstrap_external • importlib.abc • importlib.machinery • importlib.metadata • importlib.readers • importlib.resources • importlib.resources._common • importlib.util • inspect • serial

importlib._abc SourceModule

imports: abc • importlib • importlib._bootstrap • warnings

imported by: importlib.abc • importlib.util

importlib._bootstrap SourceModule

imports: _frozen_importlib_external • importlib

imported by: importlib • importlib._abc • importlib.machinery • importlib.util

importlib._bootstrap_external SourceModule

imports: _imp • _io • _warnings • importlib • importlib.metadata • importlib.readers • marshal • nt • posix • sys • tokenize • winreg

imported by: importlib • importlib.abc • importlib.machinery • importlib.util • py_compile

importlib.abc SourceModule

imports: _frozen_importlib • _frozen_importlib_external • abc • importlib • importlib._abc • importlib._bootstrap_external • importlib.machinery • importlib.resources.abc • warnings

imported by: importlib.metadata

importlib.machinery SourceModule

imports: importlib • importlib._bootstrap • importlib._bootstrap_external

imported by: importlib.abc • inspect • py_compile

importlib.metadata Package

imports: abc • collections • contextlib • csv • email • functools • importlib • importlib.abc • importlib.metadata • importlib.metadata._adapters • importlib.metadata._collections • importlib.metadata._functools • importlib.metadata._itertools • importlib.metadata._meta • itertools • operator • os • pathlib • posixpath • re • sys • textwrap • typing • warnings • zipfile

imported by: importlib._bootstrap_external • importlib.metadata • importlib.metadata._adapters • importlib.metadata._collections • importlib.metadata._functools • importlib.metadata._itertools • importlib.metadata._meta • importlib.metadata._text

importlib.metadata._adapters SourceModule

imports: email.message • importlib.metadata • importlib.metadata._text • re • textwrap

imported by: importlib.metadata

importlib.metadata._collections SourceModule

imports: collections • importlib.metadata

imported by: importlib.metadata

importlib.metadata._functools SourceModule

imports: functools • importlib.metadata • types

imported by: importlib.metadata • importlib.metadata._text

importlib.metadata._itertools SourceModule

imports: importlib.metadata • itertools

imported by: importlib.metadata

importlib.metadata._meta SourceModule

imports: importlib.metadata • typing

imported by: importlib.metadata

importlib.metadata._text SourceModule

imports: importlib.metadata • importlib.metadata._functools • re

imported by: importlib.metadata._adapters

importlib.readers SourceModule

imports: importlib • importlib.resources.readers

imported by: importlib._bootstrap_external

importlib.resources Package

imports: importlib • importlib.resources • importlib.resources._common • importlib.resources._legacy • importlib.resources.abc

imported by: importlib.resources • importlib.resources._adapters • importlib.resources._common • importlib.resources._itertools • importlib.resources._legacy • importlib.resources.abc • importlib.resources.readers

importlib.resources._adapters SourceModule

imports: contextlib • importlib.resources • importlib.resources.abc • io

imported by: importlib.resources._common

importlib.resources._common SourceModule

imports: contextlib • functools • importlib • importlib.resources • importlib.resources._adapters • importlib.resources.abc • os • pathlib • tempfile • types • typing

imported by: importlib.resources • importlib.resources._legacy

importlib.resources._itertools SourceModule

imports: importlib.resources • itertools • typing

imported by: importlib.resources.readers

importlib.resources._legacy SourceModule

imports: functools • importlib.resources • importlib.resources._common • os • pathlib • types • typing • warnings

imported by: importlib.resources

importlib.resources.abc SourceModule

imports: abc • importlib.resources • io • os • typing

imported by: importlib.abc • importlib.resources • importlib.resources._adapters • importlib.resources._common • importlib.resources.readers

importlib.resources.readers SourceModule

imports: collections • importlib.resources • importlib.resources._itertools • importlib.resources.abc • operator • pathlib • zipfile

imported by: importlib.readers

importlib.util SourceModule

imports: _imp • contextlib • functools • importlib • importlib._abc • importlib._bootstrap • importlib._bootstrap_external • sys • threading • types • warnings

imported by: py_compile • zipfile

inspect SourceModule

imports: abc • argparse • ast • builtins • collections • collections.abc • dis • enum • functools • importlib • importlib.machinery • itertools • keyword • linecache • operator • os • re • sys • token • tokenize • types

imported by: ast • dataclasses • pyi_rth_inspect.py

io SourceModule

imports: _io • abc • warnings

imported by: Cali_GUI_V8.py • _compression • bz2 • csv • dis • email.feedparser • email.generator • email.iterators • email.message • email.parser • encodings.quopri_codec • encodings.uu_codec • gzip • importlib.resources._adapters • importlib.resources.abc • logging • lzma • os • pathlib • pickle • pprint • quopri • serial.serialutil • socket • subprocess • tarfile • tempfile • tokenize • zipfile

ipaddress SourceModule

imports: functools • re

imported by: urllib.parse

itertools (builtin module)

imported by: _pydecimal • calendar • collections • dataclasses • glob • importlib.metadata • importlib.metadata._itertools • importlib.resources._itertools • inspect • pickle • random • reprlib • statistics • threading • tokenize • traceback • weakref • zipfile

keyword SourceModule

imported by: Cali_GUI_V8.py • collections • dataclasses • inspect

linecache SourceModule

imports: functools • os • sys • tokenize

imported by: Cali_GUI_V8.py • inspect • traceback • tracemalloc • warnings

locale SourceModule

imports: _collections_abc • _locale • builtins • encodings • encodings.aliases • functools • os • re • sys • warnings

imported by: Cali_GUI_V8.py • _pydecimal • _strptime • calendar • gettext • subprocess

logging Package

imports: atexit • collections.abc • io • os • pickle • re • string • sys • threading • time • traceback • types • warnings • weakref

imported by: hashlib

lzma SourceModule

imports: _compression • _lzma • builtins • io • os

imported by: shutil • tarfile • zipfile

marshal (builtin module)

imported by: importlib._bootstrap_external

math (builtin module)

imported by: _pydecimal • datetime • fractions • random • selectors • statistics

msvcrt (builtin module)

imported by: subprocess

nt (builtin module)

imported by: ctypes • importlib._bootstrap_external • ntpath • os • shutil

ntpath SourceModule

imports: _winapi • genericpath • nt • os • stat • string • sys

imported by: Cali_GUI_V8.py • os • os.path • pathlib

numbers SourceModule

imports: abc

imported by: _pydecimal • fractions • statistics

opcode SourceModule

imports: _opcode

imported by: dis

operator SourceModule

imports: _operator • builtins • functools

imported by: Cali_GUI_V8.py • collections • copyreg • datetime • email._header_value_parser • enum • fractions • gettext • importlib.metadata • importlib.resources.readers • inspect • pathlib • random • statistics • typing

org MissingModule

imported by: pickle

os SourceModule

imports: _collections_abc • abc • io • nt • ntpath • os.path • posix • posixpath • stat • subprocess • sys • warnings

imported by: Cali_GUI_V8.py • argparse • bz2 • contextlib • ctypes • email.utils • fnmatch • genericpath • getopt • gettext • glob • gzip • importlib.metadata • importlib.resources._common • importlib.resources._legacy • importlib.resources.abc • inspect • linecache • locale • logging • lzma • ntpath • os.path • pathlib • posixpath • py_compile • pyi_rth__tkinter.py • pyi_rth_inspect.py • random • serial • serial.serialposix • serial.tools.list_ports • serial.tools.list_ports_common • serial.tools.list_ports_linux • serial.tools.list_ports_posix • shutil • socket • subprocess • tarfile • tempfile • threading • tkinter • zipfile

os.path AliasNode

imports: ntpath • os

imported by: os • py_compile • serial.tools.list_ports_common • tracemalloc

pathlib SourceModule

imports: _collections_abc • errno • fnmatch • functools • grp • io • ntpath • operator • os • posixpath • pwd • re • stat • sys • urllib.parse • warnings

imported by: importlib.metadata • importlib.resources._common • importlib.resources._legacy • importlib.resources.readers • zipfile

pickle SourceModule

imports: _compat_pickle • _pickle • codecs • copyreg • functools • io • itertools • org • pprint • re • struct • sys • types

imported by: logging • tracemalloc

posix MissingModule

imports: resource

imported by: importlib._bootstrap_external • os • posixpath • shutil

posixpath SourceModule

imports: genericpath • os • posix • pwd • re • stat • sys

imported by: Cali_GUI_V8.py • fnmatch • importlib.metadata • os • pathlib • zipfile

pprint SourceModule

imports: collections • dataclasses • io • re • sys • time • types

imported by: pickle

pwd MissingModule

imported by: pathlib • posixpath • shutil • subprocess • tarfile

py_compile SourceModule

imports: argparse • enum • importlib._bootstrap_external • importlib.machinery • importlib.util • os • os.path • sys • traceback

imported by: zipfile

queue SourceModule

imports: _queue • collections • heapq • threading • time • types

imported by: Cali_GUI_V8.py

quopri SourceModule

imports: binascii • getopt • io • sys

imported by: email.encoders • email.message • encodings.quopri_codec

random SourceModule

imports: _collections_abc • _random • _sha512 • bisect • hashlib • itertools • math • operator • os • statistics • time • warnings

imported by: email.generator • email.utils • statistics • tempfile

re Package

imports: copyreg • enum • functools • re • re._compiler • re._constants • re._parser • warnings

imported by: Cali_GUI_V8.py • _pydecimal • _sre • _strptime • argparse • base64 • csv • dataclasses • email._encoded_words • email._header_value_parser • email.feedparser • email.generator • email.header • email.message • email.policy • email.quoprimime • email.utils • encodings.idna • fnmatch • fractions • gettext • glob • importlib.metadata • importlib.metadata._adapters • importlib.metadata._text • inspect • ipaddress • locale • logging • pathlib • pickle • posixpath • pprint • re • re._casefix • re._compiler • re._constants • re._parser • serial.tools.list_ports • serial.tools.list_ports_common • serial.tools.list_ports_windows • sre_compile • sre_constants • sre_parse • string • tarfile • textwrap • tkinter • tokenize • typing • urllib.parse • warnings

re._casefix SourceModule

imports: re

imported by: Cali_GUI_V8.py • re._compiler

re._compiler SourceModule

imports: _sre • re • re._casefix • re._constants • re._parser • sys

imported by: Cali_GUI_V8.py • re • sre_compile

re._constants SourceModule

imports: _sre • re

imported by: Cali_GUI_V8.py • re • re._compiler • re._parser • sre_constants

re._parser SourceModule

imports: re • re._constants • unicodedata • warnings

imported by: Cali_GUI_V8.py • re • re._compiler • sre_parse

reprlib SourceModule

imports: _thread • builtins • itertools

imported by: Cali_GUI_V8.py • collections • functools

resource MissingModule

imported by: posix

select C:\Users\ashan\AppData\Local\Programs\Python\Python311\DLLs\select.pyd

imported by: selectors • serial.serialposix • subprocess

selectors SourceModule

imports: abc • collections • collections.abc • math • select • sys

imported by: socket • subprocess

serial Package

imports: __future__ • importlib • os • serial.serialcli • serial.serialjava • serial.serialposix • serial.serialutil • serial.serialwin32 • serial.win32 • sys

imported by: Cali_GUI_V8.py • serial.serialcli • serial.serialjava • serial.serialposix • serial.serialutil • serial.serialwin32 • serial.tools • serial.tools.list_ports_posix • serial.tools.list_ports_windows • serial.win32

serial.serialcli SourceModule

imports: 'System.IO' • System • __future__ • serial • serial.serialutil

imported by: serial

serial.serialjava SourceModule

imports: __future__ • serial • serial.serialutil

imported by: serial

serial.serialposix SourceModule

imports: __future__ • array • errno • fcntl • os • select • serial • serial.serialutil • struct • sys • termios • warnings

imported by: serial

serial.serialutil SourceModule

imports: __future__ • array • io • serial • sys • time

imported by: serial • serial.serialcli • serial.serialjava • serial.serialposix • serial.serialwin32

serial.serialwin32 SourceModule

imports: __future__ • ctypes • serial • serial.serialutil • serial.win32 • time

imported by: serial

serial.tools Package

imports: serial • serial.tools.list_ports_common

imported by: serial.tools.list_ports • serial.tools.list_ports_common • serial.tools.list_ports_linux • serial.tools.list_ports_osx • serial.tools.list_ports_posix • serial.tools.list_ports_windows

serial.tools.list_ports SourceModule

imports: __future__ • argparse • os • re • serial.tools • serial.tools.list_ports_posix • serial.tools.list_ports_windows • sys

imported by: Cali_GUI_V8.py

serial.tools.list_ports_common SourceModule

imports: __future__ • glob • os • os.path • re • serial.tools

imported by: serial.tools • serial.tools.list_ports_linux • serial.tools.list_ports_osx • serial.tools.list_ports_posix • serial.tools.list_ports_windows

serial.tools.list_ports_linux SourceModule

imports: __future__ • glob • os • serial.tools • serial.tools.list_ports_common

imported by: serial.tools.list_ports_posix

serial.tools.list_ports_osx SourceModule

imports: __future__ • ctypes • serial.tools • serial.tools.list_ports_common

imported by: serial.tools.list_ports_posix

serial.tools.list_ports_posix SourceModule

imports: __future__ • glob • os • serial • serial.tools • serial.tools.list_ports_common • serial.tools.list_ports_linux • serial.tools.list_ports_osx • sys

imported by: serial.tools.list_ports

serial.tools.list_ports_windows SourceModule

imports: __future__ • ctypes • ctypes.wintypes • re • serial • serial.tools • serial.tools.list_ports_common • serial.win32

imported by: serial.tools.list_ports

serial.win32 SourceModule

imports: __future__ • ctypes • ctypes.wintypes • serial

imported by: serial • serial.serialwin32 • serial.tools.list_ports_windows

shutil SourceModule

imports: bz2 • collections • errno • fnmatch • grp • lzma • nt • os • posix • pwd • stat • sys • tarfile • zipfile • zlib

imported by: argparse • tarfile • tempfile • zipfile

signal SourceModule

imports: _signal • enum

imported by: subprocess

socket SourceModule

imports: _socket • array • enum • errno • io • os • selectors • sys

imported by: email.utils

sre_compile SourceModule

imports: re • re._compiler • warnings

imported by: Cali_GUI_V8.py

sre_constants SourceModule

imports: re • re._constants • warnings

imported by: Cali_GUI_V8.py

sre_parse SourceModule

imports: re • re._parser • warnings

imported by: Cali_GUI_V8.py

stat SourceModule

imports: _stat

imported by: Cali_GUI_V8.py • genericpath • glob • ntpath • os • pathlib • posixpath • shutil • tarfile • tempfile • zipfile

statistics SourceModule

imports: _statistics • bisect • collections • decimal • fractions • functools • itertools • math • numbers • operator • random • sys

imported by: random

string SourceModule

imports: _string • collections • re

imported by: email._encoded_words • email._header_value_parser • email.quoprimime • logging • ntpath

stringprep SourceModule

imports: unicodedata

imported by: encodings.idna

struct SourceModule

imports: _struct

imported by: base64 • ctypes • gettext • gzip • pickle • serial.serialposix • tarfile • zipfile

subprocess SourceModule

imports: _posixsubprocess • _winapi • builtins • contextlib • errno • fcntl • grp • io • locale • msvcrt • os • pwd • select • selectors • signal • sys • threading • time • types • warnings

imported by: os

sys (builtin module)

imported by: _collections_abc • _compression • _pydecimal • argparse • ast • base64 • calendar • codecs • collections • contextlib • ctypes • ctypes._endian • dataclasses • datetime • dis • email._header_value_parser • email.generator • email.iterators • email.policy • encodings • encodings.rot_13 • encodings.utf_16 • encodings.utf_32 • enum • fractions • getopt • gettext • glob • gzip • importlib • importlib._bootstrap_external • importlib.metadata • importlib.util • inspect • linecache • locale • logging • ntpath • os • pathlib • pickle • posixpath • pprint • py_compile • pyi_rth__tkinter.py • pyi_rth_inspect.py • quopri • re._compiler • selectors • serial • serial.serialposix • serial.serialutil • serial.tools.list_ports • serial.tools.list_ports_posix • shutil • socket • statistics • subprocess • tarfile • tempfile • threading • tkinter • tokenize • traceback • types • typing • urllib.parse • warnings • weakref • zipfile

tarfile SourceModule

imports: argparse • builtins • bz2 • copy • grp • gzip • io • lzma • os • pwd • re • shutil • stat • struct • sys • time • warnings • zlib

imported by: shutil

tempfile SourceModule

imports: _thread • errno • functools • io • os • random • shutil • stat • sys • types • warnings • weakref

imported by: importlib.resources._common

termios MissingModule

imported by: serial.serialposix

textwrap SourceModule

imports: re

imported by: argparse • importlib.metadata • importlib.metadata._adapters • traceback

threading SourceModule

imports: _collections • _thread • _threading_local • _weakrefset • collections • functools • itertools • os • sys • time • traceback • warnings

imported by: Cali_GUI_V8.py • _threading_local • importlib.util • logging • queue • subprocess • zipfile

time (builtin module)

imports: _strptime

imported by: Cali_GUI_V8.py • _datetime • _strptime • datetime • email._parseaddr • email.generator • email.utils • gc • gzip • logging • pprint • queue • random • serial.serialutil • serial.serialwin32 • subprocess • tarfile • threading • zipfile

tkinter Package

imports: _tkinter • collections • enum • os • re • sys • tkinter.constants • tkinter.messagebox • tkinter.ttk • traceback • types

imported by: Cali_GUI_V8.py • tkinter.commondialog • tkinter.constants • tkinter.messagebox • tkinter.ttk

tkinter.commondialog SourceModule

imports: tkinter

imported by: tkinter.messagebox

tkinter.constants SourceModule

imports: tkinter

imported by: tkinter

tkinter.messagebox SourceModule

imports: tkinter • tkinter.commondialog

imported by: Cali_GUI_V8.py • tkinter

tkinter.ttk SourceModule

imports: tkinter

imported by: Cali_GUI_V8.py • tkinter

token SourceModule

imported by: inspect • tokenize

tokenize SourceModule

imports: _tokenize • argparse • builtins • codecs • collections • functools • io • itertools • re • sys • token

imported by: importlib._bootstrap_external • inspect • linecache

traceback SourceModule

imports: ast • collections.abc • contextlib • itertools • linecache • sys • textwrap • unicodedata

imported by: Cali_GUI_V8.py • logging • py_compile • threading • tkinter • warnings

tracemalloc SourceModule

imports: _tracemalloc • collections.abc • fnmatch • functools • linecache • os.path • pickle

imported by: warnings

types SourceModule

imports: _collections_abc • functools • sys

imported by: Cali_GUI_V8.py • _weakrefset • contextlib • copy • ctypes • dataclasses • dis • email.headerregistry • enum • functools • importlib.metadata._functools • importlib.resources._common • importlib.resources._legacy • importlib.util • inspect • logging • pickle • pprint • queue • subprocess • tempfile • tkinter • typing • urllib.parse

typing SourceModule

imports: _typing • abc • collections • collections.abc • contextlib • functools • operator • re • sys • types • warnings

imported by: functools • importlib.metadata • importlib.metadata._meta • importlib.resources._common • importlib.resources._itertools • importlib.resources._legacy • importlib.resources.abc

unicodedata C:\Users\ashan\AppData\Local\Programs\Python\Python311\DLLs\unicodedata.pyd

imported by: encodings.idna • re._parser • stringprep • traceback • urllib.parse

urllib Package

imported by: email._header_value_parser • urllib.parse

urllib.parse SourceModule

imports: collections • functools • ipaddress • re • sys • types • unicodedata • urllib • warnings

imported by: email.utils • pathlib

warnings SourceModule

imports: _warnings • builtins • linecache • re • sys • traceback • tracemalloc

imported by: Cali_GUI_V8.py • argparse • ast • enum • gettext • gzip • hashlib • importlib • importlib._abc • importlib.abc • importlib.metadata • importlib.resources._legacy • importlib.util • io • locale • logging • os • pathlib • random • re • re._parser • serial.serialposix • sre_compile • sre_constants • sre_parse • subprocess • tarfile • tempfile • threading • typing • urllib.parse • zipfile

weakref SourceModule

imports: _collections_abc • _weakref • _weakrefset • atexit • copy • gc • itertools • sys

imported by: Cali_GUI_V8.py • _threading_local • copy • functools • logging • tempfile

winreg (builtin module)

imported by: importlib._bootstrap_external

zipfile SourceModule

imports: argparse • binascii • bz2 • contextlib • importlib.util • io • itertools • lzma • os • pathlib • posixpath • py_compile • shutil • stat • struct • sys • threading • time • warnings • zlib

imported by: importlib.metadata • importlib.resources.readers • pyi_rth_inspect.py • shutil

zlib (builtin module)

imported by: encodings.zlib_codec • gzip • shutil • tarfile • zipfile

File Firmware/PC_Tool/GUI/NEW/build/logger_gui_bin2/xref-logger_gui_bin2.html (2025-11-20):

# modulegraph cross reference for logger_gui_bin2.py, pyi_rth__tkinter.py, pyi_rth_inspect.py, pyi_rth_mplconfig.py, pyi_rth_multiprocessing.py, pyi_rth_pkgutil.py

logger_gui_bin2.py Script

imports: _collections_abc • _weakrefset • abc • codecs • collections • collections.abc • copyreg • datetime • encodings • encodings.aliases • encodings.ascii • encodings.base64_codec • encodings.big5 • encodings.big5hkscs • encodings.bz2_codec • encodings.charmap • encodings.cp037 • encodings.cp1006 • encodings.cp1026 • encodings.cp1125 • encodings.cp1140 • encodings.cp1250 • encodings.cp1251 • encodings.cp1252 • encodings.cp1253 • encodings.cp1254 • encodings.cp1255 • encodings.cp1256 • encodings.cp1257 • encodings.cp1258 • encodings.cp273 • encodings.cp424 • encodings.cp437 • encodings.cp500 • encodings.cp720 • encodings.cp737 • encodings.cp775 • encodings.cp850 • encodings.cp852 • encodings.cp855 • encodings.cp856 • encodings.cp857 • encodings.cp858 • encodings.cp860 • encodings.cp861 • encodings.cp862 • encodings.cp863 • encodings.cp864 • encodings.cp865 • encodings.cp866 • encodings.cp869 • encodings.cp874 • encodings.cp875 • encodings.cp932 • encodings.cp949 • encodings.cp950 • encodings.euc_jis_2004 • encodings.euc_jisx0213 • encodings.euc_jp • encodings.euc_kr • encodings.gb18030 • encodings.gb2312 • encodings.gbk • encodings.hex_codec • encodings.hp_roman8 • encodings.hz • encodings.idna • encodings.iso2022_jp • encodings.iso2022_jp_1 • encodings.iso2022_jp_2 • encodings.iso2022_jp_2004 • encodings.iso2022_jp_3 • encodings.iso2022_jp_ext • encodings.iso2022_kr • encodings.iso8859_1 • encodings.iso8859_10 • encodings.iso8859_11 • encodings.iso8859_13 • encodings.iso8859_14 • encodings.iso8859_15 • encodings.iso8859_16 • encodings.iso8859_2 • encodings.iso8859_3 • encodings.iso8859_4 • encodings.iso8859_5 • encodings.iso8859_6 • encodings.iso8859_7 • encodings.iso8859_8 • encodings.iso8859_9 • encodings.johab • encodings.koi8_r • encodings.koi8_t • encodings.koi8_u • encodings.kz1048 • encodings.latin_1 • encodings.mac_arabic • encodings.mac_croatian • encodings.mac_cyrillic • encodings.mac_farsi • encodings.mac_greek • encodings.mac_iceland • encodings.mac_latin2 • encodings.mac_roman • encodings.mac_romanian • encodings.mac_turkish • encodings.mbcs • encodings.oem • encodings.palmos • encodings.ptcp154 • encodings.punycode • encodings.quopri_codec • encodings.raw_unicode_escape • encodings.rot_13 • encodings.shift_jis • encodings.shift_jis_2004 • encodings.shift_jisx0213 • encodings.tis_620 • encodings.undefined • encodings.unicode_escape • encodings.utf_16 • encodings.utf_16_be • encodings.utf_16_le • encodings.utf_32 • encodings.utf_32_be • encodings.utf_32_le • encodings.utf_7 • encodings.utf_8 • encodings.utf_8_sig • encodings.uu_codec • encodings.zlib_codec • enum • functools • genericpath • heapq • io • json • keyword • linecache • locale • matplotlib • matplotlib.backends.backend_tkagg • matplotlib.dates • matplotlib.figure • ntpath • numpy • operator • os • pandas • pathlib • posixpath • pyi_rth__tkinter.py • pyi_rth_inspect.py • pyi_rth_mplconfig.py • pyi_rth_multiprocessing.py • pyi_rth_pkgutil.py • re • re._casefix • re._compiler • re._constants • re._parser • reprlib • serial • serial.tools • serial.tools.list_ports • sre_compile • sre_constants • sre_parse • stat • struct • sys • tempfile • threading • tkinter • tkinter.filedialog • tkinter.messagebox • tkinter.scrolledtext • tkinter.ttk • traceback • types • typing • warnings • weakref

pyi_rth__tkinter.py Script

imports: os • sys

imported by: logger_gui_bin2.py

pyi_rth_inspect.py Script

imports: inspect • os • sys • zipfile

imported by: logger_gui_bin2.py

pyi_rth_mplconfig.py Script

imports: _pyi_rth_utils.tempfile • atexit • os • shutil

imported by: logger_gui_bin2.py

pyi_rth_multiprocessing.py Script

imports: multiprocessing • multiprocessing.spawn • subprocess • sys

imported by: logger_gui_bin2.py

pyi_rth_pkgutil.py Script

imports: pkgutil • pyimod02_importers

imported by: logger_gui_bin2.py

'IPython.core' MissingModule

imported by: pandas.io.formats.printing

'System.IO' MissingModule

imported by: serial.serialcli

'java.lang' MissingModule

imported by: platform • xml.sax._exceptions

'lxml.etree' MissingModule

imported by: pandas.io.formats.xml • pandas.io.html • pandas.io.xml

'lxml.html' MissingModule

imported by: pandas.io.html

'numba.core' MissingModule

imported by: pandas.core._numba.extensions

'numba.extending' MissingModule

imported by: pandas.core._numba.kernels.sum_

'numba.typed' MissingModule

imported by: pandas.core._numba.extensions

'numpy_distutils.command' MissingModule

imported by: numpy.f2py.diagnose

'numpy_distutils.cpuinfo' MissingModule

imported by: numpy.f2py.diagnose

'numpy_distutils.fcompiler' MissingModule

imported by: numpy.f2py.diagnose

'odf.config' MissingModule

imported by: pandas.io.excel._odswriter

'odf.element' MissingModule

imported by: pandas.io.excel._odfreader

'odf.namespaces' MissingModule

imported by: pandas.io.excel._odfreader

'odf.office' MissingModule

imported by: pandas.io.excel._odfreader

'odf.opendocument' MissingModule

imported by: pandas.io.excel._odfreader • pandas.io.excel._odswriter

'odf.style' MissingModule

imported by: pandas.io.excel._odswriter

'odf.table' MissingModule

imported by: pandas.io.excel._odfreader • pandas.io.excel._odswriter

'odf.text' MissingModule

imported by: pandas.io.excel._odfreader • pandas.io.excel._odswriter

'openpyxl.cell' MissingModule

imported by: pandas.io.excel._openpyxl

'openpyxl.descriptors' MissingModule

imported by: pandas.io.excel._openpyxl

'openpyxl.styles' MissingModule

imported by: pandas.io.excel._openpyxl

'openpyxl.workbook' MissingModule

imported by: pandas.io.excel._openpyxl

'org.python' MissingModule

imported by: copy • xml.sax

'pyarrow.compute' MissingModule

imported by: pandas.core.arrays._arrow_string_mixins • pandas.core.arrays.arrow.accessors • pandas.core.arrays.arrow.array • pandas.core.arrays.string_arrow • pandas.core.reshape.merge

'pyarrow.fs' MissingModule

imported by: pandas.io.orc

'pyarrow.parquet' MissingModule

imported by: pandas.io.parquet

'scipy.sparse' MissingModule

imported by: pandas.core.arrays.sparse.accessor • pandas.core.arrays.sparse.array • pandas.core.arrays.sparse.scipy_sparse

'scipy.stats' MissingModule

imported by: pandas.core.nanops • pandas.plotting._matplotlib.hist • pandas.plotting._matplotlib.misc

'sqlalchemy.engine' MissingModule

imported by: pandas.io.sql

'sqlalchemy.schema' MissingModule

imported by: pandas.io.sql

'sqlalchemy.sql' MissingModule

imported by: pandas.io.sql

'sqlalchemy.types' MissingModule

imported by: pandas.io.sql

'tornado.ioloop' MissingModule

imported by: matplotlib.backends.backend_webagg

'tornado.template' MissingModule

imported by: matplotlib.backends.backend_webagg

'tornado.web' MissingModule

imported by: matplotlib.backends.backend_webagg

'tornado.websocket' MissingModule

imported by: matplotlib.backends.backend_webagg

AppKit MissingModule

imported by: pandas.io.clipboard

Foundation MissingModule

imported by: pandas.io.clipboard

IPython MissingModule

imported by: pandas.io.formats.printing

PIL Package

imports: PIL • PIL.BmpImagePlugin • PIL.ExifTags • PIL.GifImagePlugin • PIL.GimpGradientFile • PIL.GimpPaletteFile • PIL.Image • PIL.ImageChops • PIL.ImageCms • PIL.ImageColor • PIL.ImageFile • PIL.ImageFilter • PIL.ImageMath • PIL.ImageMode • PIL.ImageOps • PIL.ImagePalette • PIL.ImageQt • PIL.ImageSequence • PIL.ImageShow • PIL.ImageTk • PIL.ImageWin • PIL.Jpeg2KImagePlugin • PIL.JpegImagePlugin • PIL.PaletteFile • PIL.PdfParser • PIL.PngImagePlugin • PIL.PpmImagePlugin • PIL.TiffImagePlugin • PIL.TiffTags • PIL._avif • PIL._imaging • PIL._imagingcms • PIL._imagingmath • PIL._imagingtk • PIL._version • PIL._webp • PIL.features • __future__

imported by: PIL • PIL.AvifImagePlugin • PIL.BlpImagePlugin • PIL.BmpImagePlugin • PIL.BufrStubImagePlugin • PIL.CurImagePlugin • PIL.DcxImagePlugin • PIL.DdsImagePlugin • PIL.EpsImagePlugin • PIL.ExifTags • PIL.FitsImagePlugin • PIL.FliImagePlugin • PIL.FpxImagePlugin • PIL.FtexImagePlugin • PIL.GbrImagePlugin • PIL.GifImagePlugin • PIL.GimpGradientFile • PIL.GimpPaletteFile • PIL.GribStubImagePlugin • PIL.Hdf5StubImagePlugin • PIL.IcnsImagePlugin • PIL.IcoImagePlugin • PIL.ImImagePlugin • PIL.Image • PIL.ImageChops • PIL.ImageCms • PIL.ImageColor • PIL.ImageFile • PIL.ImageFilter • PIL.ImageMath • PIL.ImageMode • PIL.ImageOps • PIL.ImagePalette • PIL.ImageQt • PIL.ImageSequence • PIL.ImageShow • PIL.ImageTk • PIL.ImageWin • PIL.ImtImagePlugin • PIL.IptcImagePlugin • PIL.Jpeg2KImagePlugin • PIL.JpegImagePlugin • PIL.JpegPresets • PIL.McIdasImagePlugin • PIL.MicImagePlugin • PIL.MpegImagePlugin • PIL.MpoImagePlugin • PIL.MspImagePlugin • PIL.PaletteFile • PIL.PalmImagePlugin • PIL.PcdImagePlugin • PIL.PcxImagePlugin • PIL.PdfImagePlugin • PIL.PdfParser • PIL.PixarImagePlugin • PIL.PngImagePlugin • PIL.PpmImagePlugin • PIL.PsdImagePlugin • PIL.QoiImagePlugin • PIL.SgiImagePlugin • PIL.SpiderImagePlugin • PIL.SunImagePlugin • PIL.TgaImagePlugin • PIL.TiffImagePlugin • PIL.TiffTags • PIL.WebPImagePlugin • PIL.WmfImagePlugin • PIL.XVThumbImagePlugin • PIL.XbmImagePlugin • PIL.XpmImagePlugin • PIL._avif • PIL._binary • PIL._deprecate • PIL._imaging • PIL._imagingcms • PIL._imagingmath • PIL._imagingtk • PIL._typing • PIL._util • PIL._version • PIL._webp • PIL.features • matplotlib.backends._backend_tk • matplotlib.backends.backend_webagg_core • matplotlib.colors

PIL.AvifImagePlugin SourceModule

imports: PIL • PIL.ExifTags • PIL.Image • PIL.ImageFile • PIL._avif • __future__ • io • os • typing

imported by: PIL.Image

PIL.BlpImagePlugin SourceModule

imports: PIL • PIL.Image • PIL.ImageFile • PIL.JpegImagePlugin • __future__ • abc • enum • io • os • struct • typing

imported by: PIL.Image

PIL.BmpImagePlugin SourceModule

imports: PIL • PIL.Image • PIL.ImageFile • PIL.ImagePalette • PIL._binary • __future__ • os • typing

imported by: PIL • PIL.CurImagePlugin • PIL.IcoImagePlugin • PIL.Image

PIL.BufrStubImagePlugin SourceModule

imports: PIL • PIL.Image • PIL.ImageFile • __future__ • os • typing

imported by: PIL.Image

PIL.CurImagePlugin SourceModule

imports: PIL • PIL.BmpImagePlugin • PIL.Image • PIL.ImageFile • PIL._binary • __future__

imported by: PIL.Image

PIL.DcxImagePlugin SourceModule

imports: PIL • PIL.Image • PIL.PcxImagePlugin • PIL._binary • PIL._util • __future__

imported by: PIL.Image

PIL.DdsImagePlugin SourceModule

imports: PIL • PIL.Image • PIL.ImageFile • PIL.ImagePalette • PIL._binary • __future__ • enum • io • struct • sys • typing

imported by: PIL.Image

PIL.EpsImagePlugin SourceModule

imports: PIL • PIL.Image • PIL.ImageFile • PIL._binary • __future__ • io • os • re • shutil • subprocess • sys • tempfile • typing

imported by: PIL.Image

PIL.ExifTags SourceModule

imports: PIL • __future__ • enum

imported by: PIL • PIL.AvifImagePlugin • PIL.Image • PIL.ImageFile • PIL.ImageOps • PIL.TiffImagePlugin

PIL.FitsImagePlugin SourceModule

imports: PIL • PIL.Image • PIL.ImageFile • __future__ • gzip • math

imported by: PIL.Image

PIL.FliImagePlugin SourceModule

imports: PIL • PIL.Image • PIL.ImageFile • PIL.ImagePalette • PIL._binary • PIL._util • __future__ • os

imported by: PIL.Image

PIL.FpxImagePlugin SourceModule

imports: PIL • PIL.Image • PIL.ImageFile • PIL._binary • __future__ • olefile

imported by: PIL.Image

PIL.FtexImagePlugin SourceModule

imports: PIL • PIL.Image • PIL.ImageFile • __future__ • enum • io • struct

imported by: PIL.Image

PIL.GbrImagePlugin SourceModule

imports: PIL • PIL.Image • PIL.ImageFile • PIL._binary • __future__

imported by: PIL.Image

PIL.GifImagePlugin SourceModule

imports: PIL • PIL.Image • PIL.ImageChops • PIL.ImageFile • PIL.ImageMath • PIL.ImageOps • PIL.ImagePalette • PIL.ImageSequence • PIL._binary • PIL._imaging • PIL._typing • PIL._util • __future__ • copy • enum • functools • io • itertools • math • os • subprocess • typing

imported by: PIL • PIL.Image

PIL.GimpGradientFile SourceModule

imports: PIL • PIL._binary • __future__ • math • typing

imported by: PIL • PIL.ImagePalette

PIL.GimpPaletteFile SourceModule

imports: PIL • __future__ • io • re • typing

imported by: PIL • PIL.ImagePalette

PIL.GribStubImagePlugin SourceModule

imports: PIL • PIL.Image • PIL.ImageFile • __future__ • os • typing

imported by: PIL.Image

PIL.Hdf5StubImagePlugin SourceModule

imports: PIL • PIL.Image • PIL.ImageFile • __future__ • os • typing

imported by: PIL.Image

PIL.IcnsImagePlugin SourceModule

imports: PIL • PIL.Image • PIL.ImageFile • PIL.Jpeg2KImagePlugin • PIL.PngImagePlugin • PIL._deprecate • PIL.features • __future__ • io • os • struct • sys • typing

imported by: PIL.Image

PIL.IcoImagePlugin SourceModule

imports: PIL • PIL.BmpImagePlugin • PIL.Image • PIL.ImageFile • PIL.PngImagePlugin • PIL._binary • __future__ • io • math • typing • warnings

imported by: PIL.Image

PIL.ImImagePlugin SourceModule

imports: PIL • PIL.Image • PIL.ImageFile • PIL.ImagePalette • PIL._util • __future__ • os • re • typing

imported by: PIL.Image

PIL.Image SourceModule

imports: PIL • PIL.AvifImagePlugin • PIL.BlpImagePlugin • PIL.BmpImagePlugin • PIL.BufrStubImagePlugin • PIL.CurImagePlugin • PIL.DcxImagePlugin • PIL.DdsImagePlugin • PIL.EpsImagePlugin • PIL.ExifTags • PIL.FitsImagePlugin • PIL.FliImagePlugin • PIL.FpxImagePlugin • PIL.FtexImagePlugin • PIL.GbrImagePlugin • PIL.GifImagePlugin • PIL.GribStubImagePlugin • PIL.Hdf5StubImagePlugin • PIL.IcnsImagePlugin • PIL.IcoImagePlugin • PIL.ImImagePlugin • PIL.ImageCms • PIL.ImageColor • PIL.ImageFile • PIL.ImageFilter • PIL.ImageMode • PIL.ImagePalette • PIL.ImageQt • PIL.ImageShow • PIL.ImtImagePlugin • PIL.IptcImagePlugin • PIL.Jpeg2KImagePlugin • PIL.JpegImagePlugin • PIL.McIdasImagePlugin • PIL.MicImagePlugin • PIL.MpegImagePlugin • PIL.MpoImagePlugin • PIL.MspImagePlugin • PIL.PalmImagePlugin • PIL.PcdImagePlugin • PIL.PcxImagePlugin • PIL.PdfImagePlugin • PIL.PixarImagePlugin • PIL.PngImagePlugin • PIL.PpmImagePlugin • PIL.PsdImagePlugin • PIL.QoiImagePlugin • PIL.SgiImagePlugin • PIL.SpiderImagePlugin • PIL.SunImagePlugin • PIL.TgaImagePlugin • PIL.TiffImagePlugin • PIL.TiffTags • PIL.WebPImagePlugin • PIL.WmfImagePlugin • PIL.XVThumbImagePlugin • PIL.XbmImagePlugin • PIL.XpmImagePlugin • PIL._binary • PIL._deprecate • PIL._imaging • PIL._typing • PIL._util • __future__ • abc • atexit • builtins • collections.abc • defusedxml • enum • io • logging • math • mmap • os • re • struct • sys • tempfile • types • typing • warnings • xml.etree.ElementTree

imported by: PIL • PIL.AvifImagePlugin • PIL.BlpImagePlugin • PIL.BmpImagePlugin • PIL.BufrStubImagePlugin • PIL.CurImagePlugin • PIL.DcxImagePlugin • PIL.DdsImagePlugin • PIL.EpsImagePlugin • PIL.FitsImagePlugin • PIL.FliImagePlugin • PIL.FpxImagePlugin • PIL.FtexImagePlugin • PIL.GbrImagePlugin • PIL.GifImagePlugin • PIL.GribStubImagePlugin • PIL.Hdf5StubImagePlugin • PIL.IcnsImagePlugin • PIL.IcoImagePlugin • PIL.ImImagePlugin • PIL.ImageChops • PIL.ImageCms • PIL.ImageColor • PIL.ImageFile • PIL.ImageFilter • PIL.ImageMath • PIL.ImageOps • PIL.ImagePalette • PIL.ImageQt • PIL.ImageSequence • PIL.ImageShow • PIL.ImageTk • PIL.ImageWin • PIL.ImtImagePlugin • PIL.IptcImagePlugin • PIL.Jpeg2KImagePlugin • PIL.JpegImagePlugin • PIL.McIdasImagePlugin • PIL.MicImagePlugin • PIL.MpegImagePlugin • PIL.MpoImagePlugin • PIL.MspImagePlugin • PIL.PalmImagePlugin • PIL.PcdImagePlugin • PIL.PcxImagePlugin • PIL.PdfImagePlugin • PIL.PixarImagePlugin • PIL.PngImagePlugin • PIL.PpmImagePlugin • PIL.PsdImagePlugin • PIL.QoiImagePlugin • PIL.SgiImagePlugin • PIL.SpiderImagePlugin • PIL.SunImagePlugin • PIL.TgaImagePlugin • PIL.TiffImagePlugin • PIL.WebPImagePlugin • PIL.WmfImagePlugin • PIL.XVThumbImagePlugin • PIL.XbmImagePlugin • PIL.XpmImagePlugin • PIL.features • matplotlib.backends._backend_tk • matplotlib.backends.backend_webagg_core • matplotlib.colors • matplotlib.image • matplotlib.pyplot

PIL.ImageChops SourceModule

imports: PIL • PIL.Image • __future__

imported by: PIL • PIL.GifImagePlugin • PIL.PngImagePlugin

PIL.ImageCms SourceModule

imports: PIL • PIL.Image • PIL.ImageWin • PIL._deprecate • PIL._imagingcms • PIL._typing • PIL._util • __future__ • enum • functools • operator • sys • typing

imported by: PIL • PIL.Image

PIL.ImageColor SourceModule

imports: PIL • PIL.Image • __future__ • colorsys • functools • re

imported by: PIL • PIL.Image • PIL.ImageOps • PIL.ImagePalette

PIL.ImageFile SourceModule

imports: PIL • PIL.ExifTags • PIL.Image • PIL.TiffImagePlugin • PIL._deprecate • PIL._typing • PIL._util • __future__ • abc • io • itertools • logging • mmap • os • struct • typing

imported by: PIL • PIL.AvifImagePlugin • PIL.BlpImagePlugin • PIL.BmpImagePlugin • PIL.BufrStubImagePlugin • PIL.CurImagePlugin • PIL.DdsImagePlugin • PIL.EpsImagePlugin • PIL.FitsImagePlugin • PIL.FliImagePlugin • PIL.FpxImagePlugin • PIL.FtexImagePlugin • PIL.GbrImagePlugin • PIL.GifImagePlugin • PIL.GribStubImagePlugin • PIL.Hdf5StubImagePlugin • PIL.IcnsImagePlugin • PIL.IcoImagePlugin • PIL.ImImagePlugin • PIL.Image • PIL.ImageQt • PIL.ImageTk • PIL.ImtImagePlugin • PIL.IptcImagePlugin • PIL.Jpeg2KImagePlugin • PIL.JpegImagePlugin • PIL.McIdasImagePlugin • PIL.MpegImagePlugin • PIL.MpoImagePlugin • PIL.MspImagePlugin • PIL.PalmImagePlugin • PIL.PcdImagePlugin • PIL.PcxImagePlugin • PIL.PdfImagePlugin • PIL.PixarImagePlugin • PIL.PngImagePlugin • PIL.PpmImagePlugin • PIL.PsdImagePlugin • PIL.QoiImagePlugin • PIL.SgiImagePlugin • PIL.SpiderImagePlugin • PIL.SunImagePlugin • PIL.TgaImagePlugin • PIL.TiffImagePlugin • PIL.WebPImagePlugin • PIL.WmfImagePlugin • PIL.XVThumbImagePlugin • PIL.XbmImagePlugin • PIL.XpmImagePlugin

PIL.ImageFilter SourceModule

imports: PIL • PIL.Image • PIL._imaging • PIL._typing • __future__ • abc • collections.abc • functools • types • typing

imported by: PIL • PIL.Image

PIL.ImageMath SourceModule

imports: PIL • PIL.Image • PIL._deprecate • PIL._imagingmath • __future__ • builtins • types • typing

imported by: PIL • PIL.GifImagePlugin

PIL.ImageMode SourceModule

imports: PIL • PIL._deprecate • __future__ • functools • sys • typing

imported by: PIL • PIL.Image

PIL.ImageOps SourceModule

imports: PIL • PIL.ExifTags • PIL.Image • PIL.ImageColor • PIL.ImagePalette • __future__ • collections.abc • functools • operator • re • typing

imported by: PIL • PIL.GifImagePlugin • PIL.TiffImagePlugin

PIL.ImagePalette SourceModule

imports: PIL • PIL.GimpGradientFile • PIL.GimpPaletteFile • PIL.Image • PIL.ImageColor • PIL.PaletteFile • __future__ • array • collections.abc • random • typing

imported by: PIL • PIL.BmpImagePlugin • PIL.DdsImagePlugin • PIL.FliImagePlugin • PIL.GifImagePlugin • PIL.ImImagePlugin • PIL.Image • PIL.ImageOps • PIL.Jpeg2KImagePlugin • PIL.PcxImagePlugin • PIL.PngImagePlugin • PIL.PsdImagePlugin • PIL.SunImagePlugin • PIL.TgaImagePlugin • PIL.TiffImagePlugin • PIL.XVThumbImagePlugin • PIL.XpmImagePlugin

PIL.ImageQt SourceModule

imports: PIL • PIL.Image • PIL.ImageFile • PIL._util • __future__ • io • sys • typing

imported by: PIL • PIL.Image

PIL.ImageSequence SourceModule

imports: PIL • PIL.Image • __future__ • typing

imported by: PIL • PIL.GifImagePlugin • PIL.MpoImagePlugin • PIL.PdfImagePlugin • PIL.PngImagePlugin

PIL.ImageShow SourceModule

imports: PIL • PIL.Image • __future__ • abc • os • shlex • shutil • subprocess • sys • typing

imported by: PIL • PIL.Image

PIL.ImageTk SourceModule

imports: PIL • PIL.Image • PIL.ImageFile • PIL._imagingtk • PIL._typing • __future__ • io • typing

imported by: PIL • PIL.SpiderImagePlugin • matplotlib.backends._backend_tk

PIL.ImageWin SourceModule

imports: PIL • PIL.Image • __future__

imported by: PIL • PIL.ImageCms

PIL.ImtImagePlugin SourceModule

imports: PIL • PIL.Image • PIL.ImageFile • __future__ • re

imported by: PIL.Image

PIL.IptcImagePlugin SourceModule

imports: PIL • PIL.Image • PIL.ImageFile • PIL.JpegImagePlugin • PIL.TiffImagePlugin • PIL._binary • PIL._deprecate • __future__ • collections.abc • io • typing

imported by: PIL.Image

PIL.Jpeg2KImagePlugin SourceModule

imports: PIL • PIL.Image • PIL.ImageFile • PIL.ImagePalette • PIL._binary • __future__ • collections.abc • io • os • struct • typing

imported by: PIL • PIL.IcnsImagePlugin • PIL.Image

PIL.JpegImagePlugin SourceModule

imports: PIL • PIL.Image • PIL.ImageFile • PIL.JpegPresets • PIL.MpoImagePlugin • PIL.TiffImagePlugin • PIL._binary • PIL._deprecate • __future__ • array • io • math • os • struct • subprocess • sys • tempfile • typing • warnings

imported by: PIL • PIL.BlpImagePlugin • PIL.Image • PIL.IptcImagePlugin • PIL.MpoImagePlugin

PIL.JpegPresets SourceModule

imports: PIL • __future__

imported by: PIL.JpegImagePlugin

PIL.McIdasImagePlugin SourceModule

imports: PIL • PIL.Image • PIL.ImageFile • __future__ • struct

imported by: PIL.Image

PIL.MicImagePlugin SourceModule

imports: PIL • PIL.Image • PIL.TiffImagePlugin • __future__ • olefile

imported by: PIL.Image

PIL.MpegImagePlugin SourceModule

imports: PIL • PIL.Image • PIL.ImageFile • PIL._binary • PIL._typing • __future__

imported by: PIL.Image

PIL.MpoImagePlugin SourceModule

imports: PIL • PIL.Image • PIL.ImageFile • PIL.ImageSequence • PIL.JpegImagePlugin • PIL.TiffImagePlugin • PIL._binary • PIL._util • __future__ • os • struct • typing

imported by: PIL.Image • PIL.JpegImagePlugin

PIL.MspImagePlugin SourceModule

imports: PIL • PIL.Image • PIL.ImageFile • PIL._binary • __future__ • io • struct • typing

imported by: PIL.Image

PIL.PaletteFile SourceModule

imports: PIL • PIL._binary • __future__ • typing

imported by: PIL • PIL.ImagePalette

PIL.PalmImagePlugin SourceModule

imports: PIL • PIL.Image • PIL.ImageFile • PIL._binary • __future__ • typing

imported by: PIL.Image

PIL.PcdImagePlugin SourceModule

imports: PIL • PIL.Image • PIL.ImageFile • __future__

imported by: PIL.Image

PIL.PcxImagePlugin SourceModule

imports: PIL • PIL.Image • PIL.ImageFile • PIL.ImagePalette • PIL._binary • __future__ • io • logging • typing

imported by: PIL.DcxImagePlugin • PIL.Image

PIL.PdfImagePlugin SourceModule

imports: PIL • PIL.Image • PIL.ImageFile • PIL.ImageSequence • PIL.PdfParser • PIL.features • __future__ • io • math • os • time • typing

imported by: PIL.Image

PIL.PdfParser SourceModule

imports: PIL • __future__ • calendar • codecs • collections • mmap • os • re • time • typing • zlib

imported by: PIL • PIL.PdfImagePlugin

PIL.PixarImagePlugin SourceModule

imports: PIL • PIL.Image • PIL.ImageFile • PIL._binary • __future__

imported by: PIL.Image

PIL.PngImagePlugin SourceModule

imports: PIL • PIL.Image • PIL.ImageChops • PIL.ImageFile • PIL.ImagePalette • PIL.ImageSequence • PIL._binary • PIL._deprecate • PIL._imaging • PIL._util • __future__ • collections.abc • enum • io • itertools • logging • re • struct • typing • warnings • zlib

imported by: PIL • PIL.IcnsImagePlugin • PIL.IcoImagePlugin • PIL.Image • matplotlib.colors • matplotlib.image

PIL.PpmImagePlugin SourceModule

imports: PIL • PIL.Image • PIL.ImageFile • PIL._binary • __future__ • math • typing

imported by: PIL • PIL.Image

PIL.PsdImagePlugin SourceModule

imports: PIL • PIL.Image • PIL.ImageFile • PIL.ImagePalette • PIL._binary • PIL._util • __future__ • functools • io • typing

imported by: PIL.Image

PIL.QoiImagePlugin SourceModule

imports: PIL • PIL.Image • PIL.ImageFile • PIL._binary • __future__ • os • typing

imported by: PIL.Image

PIL.SgiImagePlugin SourceModule

imports: PIL • PIL.Image • PIL.ImageFile • PIL._binary • __future__ • os • struct • typing

imported by: PIL.Image

PIL.SpiderImagePlugin SourceModule

imports: PIL • PIL.Image • PIL.ImageFile • PIL.ImageTk • PIL._util • __future__ • os • struct • sys • typing

imported by: PIL.Image

PIL.SunImagePlugin SourceModule

imports: PIL • PIL.Image • PIL.ImageFile • PIL.ImagePalette • PIL._binary • __future__

imported by: PIL.Image

PIL.TgaImagePlugin SourceModule

imports: PIL • PIL.Image • PIL.ImageFile • PIL.ImagePalette • PIL._binary • __future__ • typing • warnings

imported by: PIL.Image

PIL.TiffImagePlugin SourceModule

imports: PIL • PIL.ExifTags • PIL.Image • PIL.ImageFile • PIL.ImageOps • PIL.ImagePalette • PIL.TiffTags • PIL._binary • PIL._deprecate • PIL._typing • PIL._util • __future__ • collections.abc • fractions • io • itertools • logging • math • numbers • os • struct • typing • warnings

imported by: PIL • PIL.Image • PIL.ImageFile • PIL.IptcImagePlugin • PIL.JpegImagePlugin • PIL.MicImagePlugin • PIL.MpoImagePlugin

PIL.TiffTags SourceModule

imports: PIL • __future__ • typing

imported by: PIL • PIL.Image • PIL.TiffImagePlugin

PIL.WebPImagePlugin SourceModule

imports: PIL • PIL.Image • PIL.ImageFile • PIL._webp • __future__ • io • typing

imported by: PIL.Image

PIL.WmfImagePlugin SourceModule

imports: PIL • PIL.Image • PIL.ImageFile • PIL._binary • __future__ • typing

imported by: PIL.Image

PIL.XVThumbImagePlugin SourceModule

imports: PIL • PIL.Image • PIL.ImageFile • PIL.ImagePalette • PIL._binary • __future__

imported by: PIL.Image

PIL.XbmImagePlugin SourceModule

imports: PIL • PIL.Image • PIL.ImageFile • __future__ • re • typing

imported by: PIL.Image

PIL.XpmImagePlugin SourceModule

imports: PIL • PIL.Image • PIL.ImageFile • PIL.ImagePalette • PIL._binary • __future__ • re

imported by: PIL.Image

PIL._avif C:\Users\ashan\AppData\Local\Programs\Python\Python311\Lib\site-packages\PIL\_avif.cp311-win_amd64.pyd

imports: PIL • typing

imported by: PIL • PIL.AvifImagePlugin

PIL._binary SourceModule

imports: PIL • __future__ • struct

imported by: PIL.BmpImagePlugin • PIL.CurImagePlugin • PIL.DcxImagePlugin • PIL.DdsImagePlugin • PIL.EpsImagePlugin • PIL.FliImagePlugin • PIL.FpxImagePlugin • PIL.GbrImagePlugin • PIL.GifImagePlugin • PIL.GimpGradientFile • PIL.IcoImagePlugin • PIL.Image • PIL.IptcImagePlugin • PIL.Jpeg2KImagePlugin • PIL.JpegImagePlugin • PIL.MpegImagePlugin • PIL.MpoImagePlugin • PIL.MspImagePlugin • PIL.PaletteFile • PIL.PalmImagePlugin • PIL.PcxImagePlugin • PIL.PixarImagePlugin • PIL.PngImagePlugin • PIL.PpmImagePlugin • PIL.PsdImagePlugin • PIL.QoiImagePlugin • PIL.SgiImagePlugin • PIL.SunImagePlugin • PIL.TgaImagePlugin • PIL.TiffImagePlugin • PIL.WmfImagePlugin • PIL.XVThumbImagePlugin • PIL.XpmImagePlugin

PIL._deprecate SourceModule

imports: PIL • __future__ • warnings

imported by: PIL.IcnsImagePlugin • PIL.Image • PIL.ImageCms • PIL.ImageFile • PIL.ImageMath • PIL.ImageMode • PIL.IptcImagePlugin • PIL.JpegImagePlugin • PIL.PngImagePlugin • PIL.TiffImagePlugin • PIL.features

PIL._imaging C:\Users\ashan\AppData\Local\Programs\Python\Python311\Lib\site-packages\PIL\_imaging.cp311-win_amd64.pyd

imports: PIL • typing

imported by: PIL • PIL.GifImagePlugin • PIL.Image • PIL.ImageFilter • PIL.PngImagePlugin

PIL._imagingcms C:\Users\ashan\AppData\Local\Programs\Python\Python311\Lib\site-packages\PIL\_imagingcms.cp311-win_amd64.pyd

imports: PIL • PIL._typing • datetime • sys • typing

imported by: PIL • PIL.ImageCms

PIL._imagingmath C:\Users\ashan\AppData\Local\Programs\Python\Python311\Lib\site-packages\PIL\_imagingmath.cp311-win_amd64.pyd

imports: PIL • typing

imported by: PIL • PIL.ImageMath

PIL._imagingtk C:\Users\ashan\AppData\Local\Programs\Python\Python311\Lib\site-packages\PIL\_imagingtk.cp311-win_amd64.pyd

imports: PIL • typing

imported by: PIL • PIL.ImageTk

PIL._typing SourceModule

imports: PIL • __future__ • collections.abc • numbers • numpy.typing • os • sys • types • typing • typing_extensions

imported by: PIL.GifImagePlugin • PIL.Image • PIL.ImageCms • PIL.ImageFile • PIL.ImageFilter • PIL.ImageTk • PIL.MpegImagePlugin • PIL.TiffImagePlugin • PIL._imagingcms • PIL._util

PIL._util SourceModule

imports: PIL • PIL._typing • __future__ • os • typing

imported by: PIL.DcxImagePlugin • PIL.FliImagePlugin • PIL.GifImagePlugin • PIL.ImImagePlugin • PIL.Image • PIL.ImageCms • PIL.ImageFile • PIL.ImageQt • PIL.MpoImagePlugin • PIL.PngImagePlugin • PIL.PsdImagePlugin • PIL.SpiderImagePlugin • PIL.TiffImagePlugin

PIL._version SourceModule

imports: PIL • __future__

imported by: PIL

PIL._webp C:\Users\ashan\AppData\Local\Programs\Python\Python311\Lib\site-packages\PIL\_webp.cp311-win_amd64.pyd

imports: PIL • typing

imported by: PIL • PIL.WebPImagePlugin

PIL.features SourceModule

imports: PIL • PIL.Image • PIL._deprecate • __future__ • collections • os • sys • typing • warnings

imported by: PIL • PIL.IcnsImagePlugin • PIL.PdfImagePlugin

PyQt4 MissingModule

imported by: pandas.io.clipboard

StringIO MissingModule

imported by: six

System MissingModule

imported by: serial.serialcli

UserDict MissingModule

imported by: pytz.lazy

__future__ SourceModule

imported by: PIL • PIL.AvifImagePlugin • PIL.BlpImagePlugin • PIL.BmpImagePlugin • PIL.BufrStubImagePlugin • PIL.CurImagePlugin • PIL.DcxImagePlugin • PIL.DdsImagePlugin • PIL.EpsImagePlugin • PIL.ExifTags • PIL.FitsImagePlugin • PIL.FliImagePlugin • PIL.FpxImagePlugin • PIL.FtexImagePlugin • PIL.GbrImagePlugin • PIL.GifImagePlugin • PIL.GimpGradientFile • PIL.GimpPaletteFile • PIL.GribStubImagePlugin • PIL.Hdf5StubImagePlugin • PIL.IcnsImagePlugin • PIL.IcoImagePlugin • PIL.ImImagePlugin • PIL.Image • PIL.ImageChops • PIL.ImageCms • PIL.ImageColor • PIL.ImageFile • PIL.ImageFilter • PIL.ImageMath • PIL.ImageMode • PIL.ImageOps • PIL.ImagePalette • PIL.ImageQt • PIL.ImageSequence • PIL.ImageShow • PIL.ImageTk • PIL.ImageWin • PIL.ImtImagePlugin • PIL.IptcImagePlugin • PIL.Jpeg2KImagePlugin • PIL.JpegImagePlugin • PIL.JpegPresets • PIL.McIdasImagePlugin • PIL.MicImagePlugin • PIL.MpegImagePlugin • PIL.MpoImagePlugin • PIL.MspImagePlugin • PIL.PaletteFile • PIL.PalmImagePlugin • PIL.PcdImagePlugin • PIL.PcxImagePlugin • PIL.PdfImagePlugin • PIL.PdfParser • PIL.PixarImagePlugin • PIL.PngImagePlugin • PIL.PpmImagePlugin • PIL.PsdImagePlugin • PIL.QoiImagePlugin • PIL.SgiImagePlugin • PIL.SpiderImagePlugin • PIL.SunImagePlugin • PIL.TgaImagePlugin • PIL.TiffImagePlugin • PIL.TiffTags • PIL.WebPImagePlugin • PIL.WmfImagePlugin • PIL.XVThumbImagePlugin • PIL.XbmImagePlugin • PIL.XpmImagePlugin • PIL._binary • PIL._deprecate • PIL._typing • PIL._util • PIL._version • PIL.features • codeop • contourpy • contourpy.array • contourpy.chunk • contourpy.convert • contourpy.dechunk • contourpy.enum_util • contourpy.typecheck • contourpy.types • cycler • dateutil.parser._parser • doctest • matplotlib._mathtext • matplotlib._mathtext_data • matplotlib._text_helpers • matplotlib.font_manager • matplotlib.pyplot • packaging.version • pandas • pandas._config.config • pandas._config.dates • pandas._config.display • pandas._config.localization • pandas._testing • pandas._testing._io • pandas._testing._warnings • pandas._testing.asserters • pandas._testing.compat • pandas._testing.contexts • pandas._typing • pandas.compat • pandas.compat._constants • pandas.compat._optional • pandas.compat.compressors • pandas.compat.numpy.function • pandas.compat.pickle_compat • pandas.compat.pyarrow • pandas.core._numba.executor • pandas.core._numba.extensions • pandas.core._numba.kernels.mean_ • pandas.core._numba.kernels.min_max_ • pandas.core._numba.kernels.shared • pandas.core._numba.kernels.sum_ • pandas.core._numba.kernels.var_ • pandas.core.accessor • pandas.core.algorithms • pandas.core.apply • pandas.core.array_algos.datetimelike_accumulations • pandas.core.array_algos.masked_accumulations • pandas.core.array_algos.masked_reductions • pandas.core.array_algos.putmask • pandas.core.array_algos.quantile • pandas.core.array_algos.replace • pandas.core.array_algos.take • pandas.core.array_algos.transforms • pandas.core.arraylike • pandas.core.arrays._arrow_string_mixins • pandas.core.arrays._mixins • pandas.core.arrays._ranges • pandas.core.arrays._utils • pandas.core.arrays.arrow._arrow_utils • pandas.core.arrays.arrow.accessors • pandas.core.arrays.arrow.array • pandas.core.arrays.arrow.extension_types • pandas.core.arrays.base • pandas.core.arrays.boolean • pandas.core.arrays.categorical • pandas.core.arrays.datetimelike • pandas.core.arrays.datetimes • pandas.core.arrays.floating • pandas.core.arrays.integer • pandas.core.arrays.interval • pandas.core.arrays.masked • pandas.core.arrays.numeric • pandas.core.arrays.numpy_ • pandas.core.arrays.period • pandas.core.arrays.sparse.accessor • pandas.core.arrays.sparse.array • pandas.core.arrays.sparse.scipy_sparse • pandas.core.arrays.string_ • pandas.core.arrays.string_arrow • pandas.core.arrays.timedeltas • pandas.core.base • pandas.core.common • pandas.core.computation.align • pandas.core.computation.check • pandas.core.computation.common • pandas.core.computation.engines • pandas.core.computation.eval • pandas.core.computation.expr • pandas.core.computation.expressions • pandas.core.computation.ops • pandas.core.computation.parsing • pandas.core.computation.pytables • pandas.core.computation.scope • pandas.core.config_init • pandas.core.construction • pandas.core.dtypes.astype • pandas.core.dtypes.base • pandas.core.dtypes.cast • pandas.core.dtypes.common • pandas.core.dtypes.concat • pandas.core.dtypes.dtypes • pandas.core.dtypes.generic • pandas.core.dtypes.inference • pandas.core.dtypes.missing • pandas.core.flags • pandas.core.frame • pandas.core.generic • pandas.core.groupby.base • pandas.core.groupby.categorical • pandas.core.groupby.generic • pandas.core.groupby.groupby • pandas.core.groupby.grouper • pandas.core.groupby.indexing • pandas.core.groupby.numba_ • pandas.core.groupby.ops • pandas.core.indexers.objects • pandas.core.indexers.utils • pandas.core.indexes.accessors • pandas.core.indexes.api • pandas.core.indexes.base • pandas.core.indexes.category • pandas.core.indexes.datetimelike • pandas.core.indexes.datetimes • pandas.core.indexes.extension • pandas.core.indexes.frozen • pandas.core.indexes.interval • pandas.core.indexes.multi • pandas.core.indexes.period • pandas.core.indexes.range • pandas.core.indexes.timedeltas • pandas.core.indexing • pandas.core.interchange.buffer • pandas.core.interchange.column • pandas.core.interchange.dataframe • pandas.core.interchange.dataframe_protocol • pandas.core.interchange.from_dataframe • pandas.core.interchange.utils • pandas.core.internals.api • pandas.core.internals.array_manager • pandas.core.internals.base • pandas.core.internals.blocks • pandas.core.internals.concat • pandas.core.internals.construction • pandas.core.internals.managers • pandas.core.internals.ops • pandas.core.methods.describe • pandas.core.methods.selectn • pandas.core.methods.to_dict • pandas.core.missing • pandas.core.nanops • pandas.core.ops • pandas.core.ops.array_ops • pandas.core.ops.common • pandas.core.ops.dispatch • pandas.core.ops.docstrings • pandas.core.ops.invalid • pandas.core.ops.mask_ops • pandas.core.ops.missing • pandas.core.resample • pandas.core.reshape.concat • pandas.core.reshape.encoding • pandas.core.reshape.melt • pandas.core.reshape.merge • pandas.core.reshape.pivot • pandas.core.reshape.reshape • pandas.core.reshape.tile • pandas.core.reshape.util • pandas.core.roperator • pandas.core.sample • pandas.core.series • pandas.core.shared_docs • pandas.core.sorting • pandas.core.strings.accessor • pandas.core.strings.base • pandas.core.strings.object_array • pandas.core.tools.datetimes • pandas.core.tools.numeric • pandas.core.tools.timedeltas • pandas.core.tools.times • pandas.core.util.hashing • pandas.core.util.numba_ • pandas.core.window.common • pandas.core.window.doc • pandas.core.window.ewm • pandas.core.window.expanding • pandas.core.window.numba_ • pandas.core.window.online • pandas.core.window.rolling • pandas.errors • pandas.io._util • pandas.io.clipboards • pandas.io.common • pandas.io.excel._base • pandas.io.excel._calamine • pandas.io.excel._odfreader • pandas.io.excel._odswriter • pandas.io.excel._openpyxl • pandas.io.excel._pyxlsb • pandas.io.excel._util • pandas.io.excel._xlrd • pandas.io.excel._xlsxwriter • pandas.io.feather_format • pandas.io.formats._color_data • pandas.io.formats.console • pandas.io.formats.css • pandas.io.formats.csvs • pandas.io.formats.excel • pandas.io.formats.format • pandas.io.formats.html • pandas.io.formats.info • pandas.io.formats.printing • pandas.io.formats.string • pandas.io.formats.style • pandas.io.formats.style_render • pandas.io.formats.xml • pandas.io.gbq • pandas.io.html • pandas.io.json._json • pandas.io.json._normalize • pandas.io.json._table_schema • pandas.io.orc • pandas.io.parquet • pandas.io.parsers.arrow_parser_wrapper • pandas.io.parsers.base_parser • pandas.io.parsers.c_parser_wrapper • pandas.io.parsers.python_parser • pandas.io.parsers.readers • pandas.io.pickle • pandas.io.pytables • pandas.io.sas.sas7bdat • pandas.io.sas.sas_constants • pandas.io.sas.sas_xport • pandas.io.sas.sasreader • pandas.io.spss • pandas.io.sql • pandas.io.stata • pandas.io.xml • pandas.plotting._core • pandas.plotting._matplotlib • pandas.plotting._matplotlib.boxplot • pandas.plotting._matplotlib.converter • pandas.plotting._matplotlib.core • pandas.plotting._matplotlib.groupby • pandas.plotting._matplotlib.hist • pandas.plotting._matplotlib.misc • pandas.plotting._matplotlib.style • pandas.plotting._matplotlib.timeseries • pandas.plotting._matplotlib.tools • pandas.plotting._misc • pandas.tseries.frequencies • pandas.tseries.holiday • pandas.tseries.offsets • pandas.util._decorators • pandas.util._exceptions • pandas.util._print_versions • pandas.util._tester • pandas.util._validators • pandas.util.version • pydoc • pyparsing.actions • pyparsing.core • pyparsing.diagram • pyparsing.exceptions • pyparsing.results • serial • serial.serialcli • serial.serialjava • serial.serialposix • serial.serialutil • serial.serialwin32 • serial.tools.list_ports • serial.tools.list_ports_common • serial.tools.list_ports_linux • serial.tools.list_ports_osx • serial.tools.list_ports_posix • serial.tools.list_ports_windows • serial.win32 • six

_abc (builtin module)

imported by: abc

_aix_support SourceModule

imports: _bootsubprocess • subprocess • sys • sysconfig

imported by: sysconfig

_ast (builtin module)

imported by: ast

_asyncio C:\Users\ashan\AppData\Local\Programs\Python\Python311\DLLs\_asyncio.pyd

imported by: asyncio.events • asyncio.futures • asyncio.tasks

_bisect (builtin module)

imported by: bisect

_blake2 (builtin module)

imported by: hashlib

_bootsubprocess SourceModule

imports: os

imported by: _aix_support

_bz2 C:\Users\ashan\AppData\Local\Programs\Python\Python311\DLLs\_bz2.pyd

imported by: bz2

_codecs (builtin module)

imported by: codecs

_codecs_cn (builtin module)

imported by: encodings.gb18030 • encodings.gb2312 • encodings.gbk • encodings.hz

_codecs_hk (builtin module)

imported by: encodings.big5hkscs

_codecs_iso2022 (builtin module)

imported by: encodings.iso2022_jp • encodings.iso2022_jp_1 • encodings.iso2022_jp_2 • encodings.iso2022_jp_2004 • encodings.iso2022_jp_3 • encodings.iso2022_jp_ext • encodings.iso2022_kr

_codecs_jp (builtin module)

imported by: encodings.cp932 • encodings.euc_jis_2004 • encodings.euc_jisx0213 • encodings.euc_jp • encodings.shift_jis • encodings.shift_jis_2004 • encodings.shift_jisx0213

_codecs_kr (builtin module)

imported by: encodings.cp949 • encodings.euc_kr • encodings.johab

_codecs_tw (builtin module)

imported by: encodings.big5 • encodings.cp950

_collections (builtin module)

imported by: collections • threading

_collections_abc SourceModule

imports: abc • sys

imported by: collections • collections.abc • contextlib • locale • logger_gui_bin2.py • os • pathlib • random • types • weakref

_compat_pickle SourceModule

imported by: _pickle • pickle

_compression SourceModule

imports: io • sys

imported by: bz2 • gzip • lzma

_contextvars (builtin module)

imported by: contextvars

_csv (builtin module)

imported by: csv

_ctypes C:\Users\ashan\AppData\Local\Programs\Python\Python311\DLLs\_ctypes.pyd

imported by: ctypes • numpy._core._dtype_ctypes

_datetime (builtin module)

imports: _strptime • time

imported by: datetime

_decimal C:\Users\ashan\AppData\Local\Programs\Python\Python311\DLLs\_decimal.pyd

imported by: decimal

_dummy_thread MissingModule

imported by: numpy._core.arrayprint

_elementtree C:\Users\ashan\AppData\Local\Programs\Python\Python311\DLLs\_elementtree.pyd

imports: pyexpat • xml.etree.ElementInclude • xml.etree.ElementPath • xml.etree.ElementTree • xml.etree.cElementTree

imported by: xml.etree.ElementTree

_frozen_importlib ExcludedModule

imported by: importlib • importlib.abc • zipimport

_frozen_importlib_external MissingModule

imported by: importlib • importlib._bootstrap • importlib.abc • zipimport

_functools (builtin module)

imported by: functools

_hashlib C:\Users\ashan\AppData\Local\Programs\Python\Python311\DLLs\_hashlib.pyd

imported by: hashlib • hmac

_heapq (builtin module)

imported by: heapq

_imp (builtin module)

imported by: importlib • importlib._bootstrap_external • importlib.util • sysconfig • zipimport

_io (builtin module)

imported by: importlib._bootstrap_external • io • zipimport

_json (builtin module)

imports: json.decoder

imported by: json.decoder • json.encoder • json.scanner

_locale (builtin module)

imported by: locale

_lzma C:\Users\ashan\AppData\Local\Programs\Python\Python311\DLLs\_lzma.pyd

imported by: lzma

_md5 (builtin module)

imported by: hashlib

_multibytecodec (builtin module)

imported by: encodings.big5 • encodings.big5hkscs • encodings.cp932 • encodings.cp949 • encodings.cp950 • encodings.euc_jis_2004 • encodings.euc_jisx0213 • encodings.euc_jp • encodings.euc_kr • encodings.gb18030 • encodings.gb2312 • encodings.gbk • encodings.hz • encodings.iso2022_jp • encodings.iso2022_jp_1 • encodings.iso2022_jp_2 • encodings.iso2022_jp_2004 • encodings.iso2022_jp_3 • encodings.iso2022_jp_ext • encodings.iso2022_kr • encodings.johab • encodings.shift_jis • encodings.shift_jis_2004 • encodings.shift_jisx0213

_multiprocessing C:\Users\ashan\AppData\Local\Programs\Python\Python311\DLLs\_multiprocessing.pyd

imported by: multiprocessing.connection • multiprocessing.queues • multiprocessing.resource_tracker • multiprocessing.synchronize

_opcode (builtin module)

imported by: opcode

_operator (builtin module)

imported by: hmac • operator

_overlapped C:\Users\ashan\AppData\Local\Programs\Python\Python311\DLLs\_overlapped.pyd

imported by: asyncio.windows_events

_pickle (builtin module)

imports: _compat_pickle • codecs • copyreg

imported by: pickle

_posixshmem MissingModule

imported by: multiprocessing.resource_tracker • multiprocessing.shared_memory

_posixsubprocess MissingModule

imports: gc

imported by: multiprocessing.util • subprocess

_py_abc SourceModule

imports: _weakrefset

imported by: abc

_pydecimal SourceModule

imports: collections • contextvars • itertools • locale • math • numbers • re • sys

imported by: decimal

_pyi_rth_utils Package

imports: _pyi_rth_utils • _pyi_rth_utils._win32 • os • sys

imported by: _pyi_rth_utils • _pyi_rth_utils._win32 • _pyi_rth_utils.tempfile

_pyi_rth_utils._win32 SourceModule

imports: _pyi_rth_utils • ctypes • ctypes.wintypes

imported by: _pyi_rth_utils • _pyi_rth_utils.tempfile

_pyi_rth_utils.tempfile SourceModule

imports: _pyi_rth_utils • _pyi_rth_utils._win32 • errno • os • sys • tempfile

imported by: pyi_rth_mplconfig.py

_queue C:\Users\ashan\AppData\Local\Programs\Python\Python311\DLLs\_queue.pyd

imported by: queue

_random (builtin module)

imported by: random

_scproxy MissingModule

imported by: urllib.request

_sha1 (builtin module)

imported by: hashlib

_sha256 (builtin module)

imported by: hashlib

_sha3 (builtin module)

imported by: hashlib

_sha512 (builtin module)

imported by: hashlib • random

_signal (builtin module)

imported by: signal

_socket C:\Users\ashan\AppData\Local\Programs\Python\Python311\DLLs\_socket.pyd

imported by: socket

_sqlite3 C:\Users\ashan\AppData\Local\Programs\Python\Python311\DLLs\_sqlite3.pyd

imported by: sqlite3.dbapi2

_sre (builtin module)

imports: copy • re

imported by: re._compiler • re._constants

_ssl C:\Users\ashan\AppData\Local\Programs\Python\Python311\DLLs\_ssl.pyd

imports: socket

imported by: ssl

_stat (builtin module)

imported by: stat

_statistics (builtin module)

imported by: statistics

_string (builtin module)

imported by: string

_strptime SourceModule

imports: _thread • calendar • datetime • locale • re • time

imported by: _datetime • datetime • time

_struct (builtin module)

imported by: struct

_thread (builtin module)

imported by: _strptime • asyncio.base_futures • dataclasses • functools • numpy._core.arrayprint • reprlib • six.moves._thread • tempfile • threading

_threading_local SourceModule

imports: contextlib • threading • weakref

imported by: threading

_tkinter C:\Users\ashan\AppData\Local\Programs\Python\Python311\DLLs\_tkinter.pyd

imported by: tkinter

_tokenize (builtin module)

imported by: tokenize

_tracemalloc (builtin module)

imported by: tracemalloc

_typeshed MissingModule

imported by: numpy.random.bit_generator

_typing (builtin module)

imported by: typing

_uuid C:\Users\ashan\AppData\Local\Programs\Python\Python311\DLLs\_uuid.pyd

imported by: uuid

_warnings (builtin module)

imported by: importlib._bootstrap_external • warnings • zipimport

_weakref (builtin module)

imported by: _weakrefset • collections • weakref • xml.sax.expatreader

_weakrefset SourceModule

imports: _weakref • types

imported by: _py_abc • logger_gui_bin2.py • multiprocessing.process • threading • weakref

_winapi (builtin module)

imported by: asyncio.windows_events • asyncio.windows_utils • encodings • mimetypes • multiprocessing.connection • multiprocessing.heap • multiprocessing.popen_spawn_win32 • multiprocessing.reduction • multiprocessing.shared_memory • multiprocessing.spawn • ntpath • subprocess

_winreg MissingModule

imported by: platform

abc SourceModule

imports: _abc • _py_abc

imported by: PIL.BlpImagePlugin • PIL.Image • PIL.ImageFile • PIL.ImageFilter • PIL.ImageShow • _collections_abc • contextlib • dataclasses • email._policybase • functools • importlib._abc • importlib.abc • importlib.metadata • importlib.resources.abc • inspect • io • logger_gui_bin2.py • matplotlib._mathtext • multiprocessing.reduction • numbers • numpy.f2py._backends._backend • numpy.polynomial._polybase • numpy.random.bit_generator • os • pandas.core.apply • pandas.core.arrays.arrow.accessors • pandas.core.computation.engines • pandas.core.indexes.datetimelike • pandas.core.interchange.dataframe_protocol • pandas.core.methods.describe • pandas.core.strings.base • pandas.io.common • pandas.io.formats.info • pandas.io.json._json • pandas.io.sas.sasreader • pandas.io.sql • pandas.plotting._matplotlib.core • pyparsing.core • selectors • typing

argparse SourceModule

imports: copy • gettext • os • re • shutil • sys • textwrap • warnings

imported by: ast • calendar • code • dis • doctest • gzip • http.server • inspect • matplotlib.dviread • numpy.f2py.f2py2e • pickletools • py_compile • serial.tools.list_ports • tarfile • tokenize • unittest.main • zipfile

array (builtin module)

imported by: PIL.ImagePalette • PIL.JpegImagePlugin • multiprocessing.dummy • multiprocessing.managers • multiprocessing.reduction • serial.serialposix • serial.serialutil • socket

ast SourceModule

imports: _ast • argparse • collections • contextlib • enum • inspect • sys • warnings

imported by: inspect • matplotlib.rcsetup • numpy._core._internal • numpy.lib._format_impl • numpy.lib._utils_impl • numpy.matrixlib.defmatrix • pandas.core.computation.expr • pandas.core.computation.pytables • traceback

asyncio Package

imports: asyncio • asyncio.DefaultEventLoopPolicy • asyncio.base_events • asyncio.base_futures • asyncio.base_subprocess • asyncio.base_tasks • asyncio.constants • asyncio.coroutines • asyncio.events • asyncio.exceptions • asyncio.format_helpers • asyncio.futures • asyncio.locks • asyncio.mixins • asyncio.proactor_events • asyncio.protocols • asyncio.queues • asyncio.runners • asyncio.selector_events • asyncio.sslproto • asyncio.staggered • asyncio.streams • asyncio.subprocess • asyncio.taskgroups • asyncio.tasks • asyncio.threads • asyncio.timeouts • asyncio.transports • asyncio.trsock • asyncio.unix_events • asyncio.windows_events • asyncio.windows_utils • sys

imported by: asyncio • asyncio.base_events • asyncio.base_futures • asyncio.base_subprocess • asyncio.base_tasks • asyncio.constants • asyncio.coroutines • asyncio.events • asyncio.exceptions • asyncio.format_helpers • asyncio.futures • asyncio.locks • asyncio.log • asyncio.mixins • asyncio.proactor_events • asyncio.protocols • asyncio.queues • asyncio.runners • asyncio.selector_events • asyncio.sslproto • asyncio.staggered • asyncio.streams • asyncio.subprocess • asyncio.taskgroups • asyncio.tasks • asyncio.threads • asyncio.timeouts • asyncio.transports • asyncio.trsock • asyncio.unix_events • asyncio.windows_events • asyncio.windows_utils • matplotlib.backends.backend_webagg • matplotlib.backends.backend_webagg_core • unittest.async_case

asyncio.DefaultEventLoopPolicy MissingModule

imported by: asyncio • asyncio.events

asyncio.base_events SourceModule

imports: asyncio • asyncio.constants • asyncio.coroutines • asyncio.events • asyncio.exceptions • asyncio.futures • asyncio.log • asyncio.protocols • asyncio.sslproto • asyncio.staggered • asyncio.tasks • asyncio.transports • asyncio.trsock • collections • collections.abc • concurrent.futures • errno • functools • heapq • itertools • os • socket • ssl • stat • subprocess • sys • threading • time • traceback • warnings • weakref

imported by: asyncio • asyncio.proactor_events • asyncio.selector_events • asyncio.unix_events

asyncio.base_futures SourceModule

imports: _thread • asyncio • asyncio.format_helpers • reprlib

imported by: asyncio • asyncio.base_tasks • asyncio.futures

asyncio.base_subprocess SourceModule

imports: asyncio • asyncio.log • asyncio.protocols • asyncio.transports • collections • subprocess • warnings

imported by: asyncio • asyncio.unix_events • asyncio.windows_events

asyncio.base_tasks SourceModule

imports: asyncio • asyncio.base_futures • asyncio.coroutines • linecache • reprlib • traceback

imported by: asyncio • asyncio.tasks

asyncio.constants SourceModule

imports: asyncio • enum

imported by: asyncio • asyncio.base_events • asyncio.format_helpers • asyncio.proactor_events • asyncio.selector_events • asyncio.sslproto • asyncio.unix_events

asyncio.coroutines SourceModule

imports: asyncio • collections.abc • inspect • os • sys • traceback • types

imported by: asyncio • asyncio.base_events • asyncio.base_tasks • asyncio.runners • asyncio.streams • asyncio.tasks • asyncio.unix_events

asyncio.events SourceModule

imports: _asyncio • asyncio • asyncio.DefaultEventLoopPolicy • asyncio.format_helpers • contextvars • os • socket • subprocess • sys • threading

imported by: asyncio • asyncio.base_events • asyncio.futures • asyncio.mixins • asyncio.runners • asyncio.selector_events • asyncio.staggered • asyncio.streams • asyncio.subprocess • asyncio.taskgroups • asyncio.tasks • asyncio.threads • asyncio.timeouts • asyncio.unix_events • asyncio.windows_events

asyncio.exceptions SourceModule

imports: asyncio

imported by: asyncio • asyncio.base_events • asyncio.futures • asyncio.locks • asyncio.proactor_events • asyncio.runners • asyncio.sslproto • asyncio.staggered • asyncio.streams • asyncio.taskgroups • asyncio.tasks • asyncio.timeouts • asyncio.unix_events • asyncio.windows_events

asyncio.format_helpers SourceModule

imports: asyncio • asyncio.constants • functools • inspect • reprlib • sys • traceback

imported by: asyncio • asyncio.base_futures • asyncio.events • asyncio.futures • asyncio.streams

asyncio.futures SourceModule

imports: _asyncio • asyncio • asyncio.base_futures • asyncio.events • asyncio.exceptions • asyncio.format_helpers • concurrent.futures • contextvars • logging • sys • types

imported by: asyncio • asyncio.base_events • asyncio.proactor_events • asyncio.selector_events • asyncio.tasks • asyncio.unix_events • asyncio.windows_events

asyncio.locks SourceModule
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

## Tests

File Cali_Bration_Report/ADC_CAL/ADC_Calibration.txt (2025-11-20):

import pandas as pd
import numpy as np
import matplotlib.pyplot as plt
from pathlib import Path

# ==============================================================
# CONFIGURATION
# ==============================================================
CSV_FILE = "ADC_Data.csv"   # <-- replace with your CSV filename
# ==============================================================

def main():
    csv_path = Path(CSV_FILE)
    if not csv_path.exists():
        print(f"❌ File not found: {csv_path}")
        return

    # --- Load and normalize columns ---
    df = pd.read_csv(csv_path)
    df.columns = [c.strip().upper() for c in df.columns]

    # Detect column names automatically
    dmm_col = [c for c in df.columns if "DMM" in c][0]
    adc_col = [c for c in df.columns if ("ADC" in c) or ("BATTERY" in c)][0]

    # Convert to numeric
    df["DMM_V"] = pd.to_numeric(df[dmm_col], errors="coerce")
    df["ADC_V"] = pd.to_numeric(df[adc_col], errors="coerce")
    df = df.dropna(subset=["DMM_V", "ADC_V"])

    x = df["ADC_V"].to_numpy()
    y = df["DMM_V"].to_numpy()

    # --- Fit linear model (DMM = a * ADC + b) ---
    a, b = np.polyfit(x, y, 1)

    # Calculate R²
    y_pred = a * x + b
    ss_res = np.sum((y - y_pred) ** 2)
    ss_tot = np.sum((y - np.mean(y)) ** 2)
    r2 = 1 - ss_res / ss_tot if ss_tot != 0 else np.nan

    # --- Print results ---
    print("\n=== Linear Calibration (DMM = a * ADC + b) ===")
    print(f"Slope (a): {a:.7f}")
    print(f"Offset (b): {b:.7f} V")
    print(f"R²: {r2:.6f}")
    print("\nFirmware #define suggestions:")
    print(f"#define CAL_SLOPE     {a:.7f}f")
    print(f"#define CAL_OFFSET_V  {b:.7f}f")

    # --- Plot ---
    plt.figure(figsize=(6, 4))
    plt.scatter(x, y, label="Measured Data", color="blue")
    plt.plot(np.linspace(min(x), max(x), 100),
             a * np.linspace(min(x), max(x), 100) + b,
             color="red", label=f"Fit: DMM = {a:.4f}×ADC + {b:.4f}")
    plt.xlabel("ADC Voltage (V)")
    plt.ylabel("DMM Voltage (V)")
    plt.title("ADC Calibration Fit")
    plt.legend()
    plt.grid(True)
    plt.tight_layout()
    plt.show()

if __name__ == "__main__":
    main()

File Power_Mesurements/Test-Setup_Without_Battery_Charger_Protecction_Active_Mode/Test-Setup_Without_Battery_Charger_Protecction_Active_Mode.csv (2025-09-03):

Timestamp(ms) | Current(uA)
0 | 1230.036
0.01 | 1685.783
0.02 | 3891.676
0.03 | 5667.050
0.04 | 7484.363
0.05 | 17177.732
0.06 | 17889.084
0.07 | 17794.078
0.08 | 17461.945
0.09 | 16563.439
0.1 | 15528.549
0.11 | 14639.513
0.12 | 13476.414
0.13 | 12505.282
0.14 | 11723.055
0.15 | 11035.771
0.16 | 10715.974
0.17 | 10487.912
0.18 | 10396.772
0.19 | 10169.137
0.2 | 10761.622
0.21 | 11218.778
0.22 | 11906.792
0.23 | 12597.540
0.24 | 13291.023
0.25 | 14219.922
0.26 | 15481.647
0.27 | 16705.018
0.28 | 17746.594
0.29 | 18460.133
0.3 | 19463.684
0.31 | 20231.891
0.32 | 20713.600
0.33 | 20761.838
0.34 | 20858.350
0.35 | 20954.910
0.36 | 21099.842
0.37 | 20761.838
0.38 | 20617.160
0.39 | 20424.428
0.4 | 20135.693
0.41 | 19895.416
0.42 | 19415.773
0.43 | 18794.055
0.44 | 18079.238
0.45 | 17083.092
0.46 | 16045.259
0.47 | 15200.498
0.48 | 14080.277
0.49 | 13383.694
0.5 | 12459.172
0.51 | 11768.971
0.52 | 11218.778
0.53 | 10852.956
0.54 | 10761.622
0.55 | 10624.713
0.56 | 10990.049
0.57 | 11081.504
0.58 | 11310.355
0.59 | 11631.259
0.6 | 11860.839
0.61 | 12090.724
0.62 | 12044.723
0.63 | 12505.282
0.64 | 12182.763
0.65 | 12182.763
0.66 | 11998.733
0.67 | 11723.055
0.68 | 11631.259
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

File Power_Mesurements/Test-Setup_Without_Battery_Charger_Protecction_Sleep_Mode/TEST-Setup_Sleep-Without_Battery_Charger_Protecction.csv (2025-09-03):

Timestamp(ms) | Current(uA)
0 | 18.711
0.01 | 18.668
0.02 | 18.711
0.03 | 18.580
0.04 | 18.711
0.05 | 18.711
0.06 | 18.843
0.07 | 18.799
0.08 | 18.624
0.09 | 18.931
0.1 | 19.019
0.11 | 18.931
0.12 | 18.887
0.13 | 18.843
0.14 | 18.887
0.15 | 18.931
0.16 | 19.019
0.17 | 18.887
0.18 | 19.019
0.19 | 18.887
0.2 | 19.107
0.21 | 19.151
0.22 | 18.931
0.23 | 18.887
0.24 | 19.019
0.25 | 18.843
0.26 | 18.975
0.27 | 19.107
0.28 | 19.151
0.29 | 19.063
0.3 | 18.975
0.31 | 19.063
0.32 | 19.019
0.33 | 19.107
0.34 | 19.107
0.35 | 19.107
0.36 | 19.151
0.37 | 19.283
0.38 | 19.239
0.39 | 19.414
0.4 | 19.239
0.41 | 19.414
0.42 | 19.283
0.43 | 19.414
0.44 | 19.326
0.45 | 19.458
0.46 | 19.370
0.47 | 19.326
0.48 | 19.502
0.49 | 19.546
0.5 | 19.414
0.51 | 19.722
0.52 | 19.678
0.53 | 19.634
0.54 | 19.634
0.55 | 19.590
0.56 | 19.590
0.57 | 19.590
0.58 | 19.854
0.59 | 19.810
0.6 | 19.854
0.61 | 19.722
0.62 | 19.985
0.63 | 19.898
0.64 | 19.941
0.65 | 19.898
0.66 | 19.985
0.67 | 19.985
0.68 | 20.029
0.69 | 20.029
0.7 | 20.029
0.71 | 20.073
0.72 | 20.205
0.73 | 20.029
0.74 | 20.117
0.75 | 20.161
0.76 | 20.205
0.77 | 20.117
0.78 | 20.293
0.79 | 20.425
0.8 | 20.337
0.81 | 20.293
0.82 | 20.381
0.83 | 20.337
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

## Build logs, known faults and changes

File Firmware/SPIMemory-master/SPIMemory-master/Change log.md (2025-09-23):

# SPIMemory
##### Change log
 






>This Arduino library is for use with flash and FRAM memory chips that communicate using the SPI protocol. In its current form it supports identifying the flash/FRAM chip and its various features; automatic address allocation and management; writing and reading a number of different types of data, ranging from 8-bit to 32-bit (signed and unsigned) values, floats, Strings, arrays of bytes/chars and structs to and from various locations; sector, block and chip erase; and powering down for low power operation.

<hr>

## Version 3.4.0

#### Release date 03.06.2019

###### Bugs squashed:
- FastRead works properly now. All previous versions of the library has a FastRead bug that prevent it from doing what it was supposed to.

###### Enhancements:
- An alternate version of the constructor
```
SPIFlash flash(int8_t *SPIPinsArray);
```
can be used (only with ESP32 boards as of now) to enable the use of custom SPI pins. ```SPIPinsArray``` has to be a 4 element array containing the custom SPI pin numbers (as signed integers - int8_t) in the following order - sck, miso, mosi, ss. Refer to the wiki for more information. Resolves #113
- Created new error code `NOCHIPSELECTDECLARED` for errors with declaring custom SPI pins.
- Using other SPI ports (HSPI, VSPI, SPI1, SPI2 etc.) is now also supported on ESP32 boards - along with SAMD and STM32 boards (supported since v3.0.0). Resolves #177
- Formatted and merged pull request #153. This changes the way [setClock()](https://github.com/Marzogh/SPIMemory/wiki/Library-instantiation-functions#setclockclockspeed) works and allows for the definition of clock speed before the SPI Bus is instantiated. Refer to [wiki](https://github.com/Marzogh/SPIMemory/wiki/Library-instantiation-functions#setclockclockspeed) for further details. Thanks @rambo.

###### New Microcontrollers supported:
- nRF52832 ARM Cortex M4F (Adafruit nRF52 Feather)
- STM32L0 ARM Cortex M0+ (Nucleo-L031K6)

###### New flash memory chips supported:
- MX25L4005 & MX25L4005 from Macronix

<hr>

## Version 3.3.0

#### Release date 20.04.2019

>Library now supports FRAM memory (In BETA). Documentation for this is in progress.

###### Bugs squashed:
- Fixed a major bug causing issues with page boundaries in writeAnything and writeStr. Thanks for your help @jacky4566 (Issue #151)
- Fixed a major bug with reading Strings (Issue #143)
- @incorvia fixed a bug by initialising the SPIBusState to false
- Fixes bug that causes ballooning of pagesize when SFDP is not read. This is because no default `_pageSize` value was set in this scenario. This has now been fixed
- Fixed a major bug in how SFDP data is used to calculate chip capacity. The previous version of the library returned a wrong value. This has now been fixed. Refer to comments in `_getSFDPFlashParam(void)` for further details.

###### Enhancements:
- Reduce SRAM footprint when running Diagnostics.ino. Thanks @rambo (PR #157)
- Officially supports the ESP32 (tested on the ESP32 Feather)
- Now supports FRAM memory chips via the `SPIFram` constructor
- Changed Diagnostics output in `_chipID()` to match situation better.
- Fixed `_chipID()` to run more efficiently.

###### New flash memory chips supported:
- GD25Q16C from Giga devices (Used on the Adafruit ItsyBitsy M0 Express)
- W25Q64JV from Winbond
- SST26VF016B & SST26VF032B from Microchip. (Thanks @mix86)

###### New FRAM memory chips supported:
- FM25W256 from Cypress

<hr>

## Version 3.2.1

#### Release date 13.04.2018

###### Bugs squashed
- Fixes issue #135 : The addition of the SFDP checking to `_chipID()` resulted in a sudden (very large) increase in compiled code size. As of the current version (v3.2.1), SFDP checking is an user controlled option. To get the library to work with SFDP compatible flash memory that is not officially supported, the user must uncomment `//#define USES_SFDP` in `SPIMemory.h`.

- Moved `bool _loopedOver` from being a local variable in `getAddress()` to a global one. Now it actually does what it was meant to do - i.e. prevent looping over data a second time.

###### Enhancements
- The way the basic functions execute has been modified to keep the function runtime the same (or improved) while reducing their memory footprint.

| Test sketch  | Test platform |
|:-----:|:-----:|
|FlashDiagnostics.ino from v3.2.0<br>with #RUNDIAGNOSTIC commented out | Arduino Pro Mini 8MHz 3.3V |

| Library version | Compiled code size<br>(Bytes) | SFDP status | Size compared to v3.1.0 |
| :---: | :---: | :---: | :-----: |
| v3.1.0 | 17652 | SFDP discovery not supported | Same size |
| v3.2.0 | 20104 | SFDP discovery supported & on by default | 13.9% larger than v3.1.0 |
| v3.2.1 | 15316 | SFDP discovery turned off | 13.75% smaller than v3.1.0 |
| v3.2.1 | 17854 | SFDP discovery turned on | 1.1% larger than v3.1.0 |

<hr>

## Version 3.2.0

#### Release date 24.01.2018

- Library name changed to SPIMemory

- The library now gathers sfdp information through `_chipID()`. SFDP information is collected when available, otherwise the library defaults to the pre v3.2.0 version.

###### New flash memory chips supported
- All flash memories compatible with the SFDP standard (as at JESD216B) should be compatible with the library

- LE25U40CMC from ON Semiconductor
- A25L512A0 from AMIC
- M25P40 from Micron
- AT25SF041 from Adesto
- S25FL032P from Cypress/Spansion

###### New Microcontrollers supported
- ATSAMD51J19 ARM Cortex M4 (Adafruit Metro M4)

###### Enhancements
The library now does the following - if the flash memory chip is compatible with the SFDP standard:
- Identifies the flash memory chip using the Serial Flash Discoverable Parameters standard. (JESD216B)
- Identifies the following opcodes from the SFDP tables and uses them to read/write data:
	- `eraseSector`
	- `eraseBlock32K`
	- `eraseBlock64K`
- Reads timing information from SFDP to accurately time the following operations:
	- `eraseSector`
	- `eraseBlock32K`
	- `eraseBlock64K`
- Fixes #125 in commit 10c2b86. The library automatically uses the alternate chip erase code (0xC7) as required (only on fully supported chips)

<hr>

## Version 3.1.0

#### Release date 24.01.2018

>Library name change notice inserted into `flash.begin()`. This notice can be dismissed by commenting out the instance of `#define PRINTNAMECHANGEALERT` in SPIFlash.h. Please refer to the Readme file for further details.

Bugs squashed
- An error with how `_addressCheck()` works with data that spans the memory boundary - when rolling over from address `_chip.capacity` to address `0x00` - has been fixed. In previous versions this caused issues with writing complex data structures across the memory boundary and led to many `_writeErrorCheck()` failures. Fixes issue #112

- An error with how `_writeErrorCheck()` worked has been resolved. Writing structs is now as stable as other functions are. Fixes #106

- All compilation-time, non-critical errors have been fixed.

###### Enhancements:
- A new function - `flash.eraseSection(address, size)` - has been introduced in this version. When a user requires a large and variable (between writes) amount of data to be written to the flash memory on the fly and to have the correct amount of space erased to fit the data, this function will automatically calculate and erase the right amount of space to fit the data. Please note that if the the amount of data being written is consistently the same size, the pre-existing `flash.eraseSector()`, `flash.eraseBlock32K()` and `flash.eraseBlock64K()` functions will operate a lot faster.
- Updated `Diagnostics.ino` to include `eraseSection()`.

- All I/O functions now check to see if the flash chip is powered down. If it is, they prevent the function from running and returns an error. A new error code 'CHIPISPOWEREDDOWN' will be returned upon calling `flash.error()`.

###### New flash memory chips supported:
- S25FL127S

<hr>

## Version 3.0.1

#### Release date 10.12.2017

###### Bugs squashed:

- Thanks for catching and fixing the following @hanyazou (PR #101)
	- Added missing break statements in `_beginSPI()` because that lacks some essential break statement in switch/case. (commit 1: 1de2c10)
	- The library did not wait until the busy bit in SR1 was cleared. Timeout argument of `_notBusy()` must be in micro-second. 500L means 500 micro seconds which is too short to wait for completion of erase command. Added " * 1000" to the arguments. (commit 2: 9633c2f)
	- Modified `TestFlash.ino` to check error of erase commands execution. (commit 3: a179306)

- Fixes a major bug that was causing input Arrays to be overwritten by zeros during the writeByteArray() / writeCharArray() process. Thanks for catching this @hanyazou. (Issue #102)

###### New flash memory chips supported:
- S25FL127S

<hr>

## Version 3.0.0

#### Release date 09.08.2017

###### Bugs Squashed:
- The `writeByteArray()` & `writeCharArray()` bug that occurred when writing arrays that spanned page boundaries (squashed in v2.5.0), stayed around to haunt the other functions. Writing any data larger than a single byte that spanned page boundaries would cause the data to wrap around to the beginning of the page. This has now been squashed in this release.

###### Deprecations:
- Going forward the ATTiny85 is no longer officially supported.
- The library no longer supports using the page number + offset combination instead of addresses. If your code requires you to use a page number + offset combination, use the following code to help
```
address = (pagenumber << 8) + offset.
(32 bit) |     (16 bit)     | (8 bit)
```
- The constructor no longer takes the pageOverflow variable as an argument. Page overflow is globally enabled by default and can be disabled by including a "#define DISABLEOVERFLOW" at the beginning of SPIFlash.h.

###### New Boards supported:
- Nucleo-F091RC
- Adafruit Feather M0

###### New Flash manufacturers supported:
- Microchip (SST25 & SST26 series)
- Cypress
- Spansion

###### Enhancements:
- Confirmed to work with SPANSION/CYPRESS & MICROCHIP (Both SST25 & SST26 series).
- If not using an officially supported chip, use the following variation of flash.begin() :
```
flash.begin(flashChipSize)
```

 where flashChipSize is indicated in Bytes, Kilobytes or Megabytes. (Refer to the next two items in this change log)

- Including 'flashChipSize' in flash.begin() compiles more efficiently than in previous versions.
- The way memory size is indicated by the users in flash.begin(flashChipSize) has changed - please refer to defines.h or the wiki for further information. The new method enables users to define any custom size unlike the previous version where only a limited number of predetermined sizes were available to use.
- Library faster than before (Refer to Library speed comparison in the extras folder for timing details):

> Improvements in speed in v3.0.0 when compared to v2.7.0 (values in percentage of time v3.0.0 is faster than v2.7.0)
>
>| Function | Change in speed |
>| :-----: | :-----: |
>| writeByte | +3% |
>| writeChar | +6% |
>| writeWord | +3% |
>| writeShort | +5% |
>| writeULong | +7% |
>| writeLong | +7% |
>| readLong | +7% |
>|  writeFloat | +7% |
>| writeStr | +57% |
>| readStr | +61% |
>| writeAnything<br>(struct) | +25% |
>| readAnything <br>(struct) | +20% |
>| writeByteArray<br>(256 bytes) | +18% |
>| readByteArray<br>(256 bytes) | +45% |
>| eraseSector | +99% |
>| eraseBlock32K | +99.4% |
>| eraseBlock64K | +99.5% |
>| eraseChip | +12% |

- Constructor changed to enable user to choose one of multiple SPI ports - if available. Look at wiki for further info
- When `RUNDIAGNOSTIC` is uncommented in SPIFlash.h, users now have access to a new function called `flash.functionRunTime()` which can be called after any library I/O function is run. `flash.functionRunTime()` returns the time taken by the previous function to run, in microseconds (as a float). An example use case can be found when the FlashDiagnostics sketch is run with `RUNDIAGNOSTIC` uncommented.
- `_notBusy()` is faster
- Completely re-written `FlashDiagnostics.ino` - uses fewer resources, compatible with more chips and boards
- All functions except the Byte/Char Array Read/Write functions now call an internal `_write`/`_read` function for increased ease of compilation, execution and troubleshooting
- Restructured the internal `_troubleshoot()` function to be better human readable and faster to compile.
- Added a function `getUniqueID()` which returns the unique ID of the flash memory chip as a 64-bit integer.
- Added an internal `_readStat3()` function to enable 4-byte addressing when using flash memory larger than 128 MB
- 4-byte addressing enabled in flash memory larger than 128 MB. This is currently only supported on the W25Q256 and W25Q512. More chips will be supported on a case-by-case basis
- `getAddress()` function now works anytime it is called - even if there is preexisting data on the chip

<hr>

## Version 2.7.0

#### Release date 17.04.2017

###### Bugs Squashed:
- ATTiny85 support available again.

###### New Boards supported:
- Arduino Zero now fully supported.

###### Enhancements:
- Compatible with the ESP32 core for Arduino as of the current commit [9618eec](https://github.com/espressif/arduino-esp32/tree/9618eec19ea470bb59b9a25ebeb8c0c516ca89cc) on 02.08.2017. For some unknown reason, SPI clock speeds higher than board speed/4 are not stable and so, the clock speed for ESP32 dev boards has currently been throttled to 20MHz.

	<small> _NOTE: ESP32 boards usually have an SPIFlash already attached to their SS pin, so the user has to declare the ChipSelect pin being used when the constructor is declared - for example
`SPIFlash flash(33);`_ </small>

<hr>

## Version 2.6.0

#### Release date 16.04.2017

###### Bugs Squashed:
- Fixed issue with reading status register 2 and the Suspend operation where the library was not checking the suspend status correctly.

###### Deletions:
- `flash.getChipName()` has been removed as it is superfluous now that the library is now on its way to multi-chip compatibility.
- Library is not compatible with the ATTiny85 anymore. Currently working on a fix which will hopefully be rolled out in v2.7.0

###### New Boards supported:
- RTL8195A compatibility tested and enabled by @boseji on 02.03.17. Code modified to fit with the library structure by Prajwal Bhattaram on 14.04.17.
- Compatible with the ESP32 core for Arduino as of the current commit [7d0968c](https://github.com/espressif/arduino-esp32/tree/7d0968c10dc540709d69a28eab2457075c1e4fa8) as on 16.04.2017. The ESP32 core currently does not support analogRead and so randomSeed(AnalogRead(A0)) cannot be used.

	<sub> For an unknown reason, SPI clock speeds higher than board speed/4 are not stable and so, the clock speed for ESP32 dev boards has currently been throttled to 20MHz. </sub>
- Added support for the Simblee module.

###### Enhancements:
- `flash.error()` now takes an optional argument 'VERBOSE'. By default the verbosity argument  is set to 'false' and calling `flash.error()` still returns the latest error code as an unsigned byte. However, running `flash.error(VERBOSE)` will not only return the latest error code, but will also print it to serial. This - especially in boards with resources to spare - will result in a detailed error report printed to serial.
- `flash.begin()` now returns a boolean value to indicate establishment of successful comms with the flash chip. Usercode can be made more efficient now by calling ```if (!flash.begin()) { Serial.println(flash.error(VERBOSE)); }``` to identify a problem as soon as the library code is run.
- The internal `_addressCheck()` function now locks up usercode with appropriate error codes if
	1. `flash.begin()` has not been called (or)
	2. There is a possible issue with the wiring - i.e. the flash chip is non-responsive (or)
	3. If the chip's capacity either cannot be identified & the user has not defined a chipSize in `flash.begin()`.
- Fixed `powerDown()`to be more efficient. The chip now powers down much faster than before.
- Added a new error code. Library can now detect non-responsive chips - bad wiring or otherwise.
- Streamlined variables to make code structure better.
- Changed library structure to enable the addition of multi-flash compatibility in the near future.
- moved `#define RUNDIAGNOSTIC` & `#define HIGHSPEED` to `SPIFlash.h` from `SPIFlash.cpp`.
- Now works with other Winbond modules (not in the official supported module list) (beta) by taking the flash memory size in bits as an argument in `flash.begin(_chipSize)`;
- Formatted code to be better human readable.
- Changed the internal `_troubleshoot()` function to use fewer resources.

<hr>

## Version 2.5.0

#### Release date 13.11.2016

###### Bugs Squashed:
- Errorchecking on `writeByteArray()` and `writeCharArray()` was broken in 2.4.0 and is fixed now.
- Previous versions (< 2.5.0) suffered from the inability to write datasets that spanned page boundaries. This has now been fixed (Ref. Enhancements section below)

###### Deletions:
- `flash.writePage()` & `flash.readPage()` have been retired as they can be duplicated - more effectively - by other functions. Refer to `pageDiag()` in `Diagnostics.ino` to see how the same results can be obtained by using `flash.writeByteArray()` & `flash.readByteArray()`.

###### Enhancements:
- Added support for SPI Transactions.
- Added an upgrade for Arduino Due users to read and write large arrays of data at very high speeds - previously reading 60kb of data would take ~108ms - it now takes ~525uS. In this mode, the time between consecutive reads has been reduced to <12ms (needs more work!).
- Completely re-written `writeByteArray()` and `writeCharArray()` functions. They no longer breakdown when writing arrays that span multiple pages.
- All functions that write more than 1 byte of data now take into account page boundaries when writing across pages. In previous versions writing across a page boundary would cause the remainder of the data to wrap around to the beginning of the page. Now the data is written seamlessly from one page over to the next.
- Calling `flash.begin()` now instantiates the SPI bus. Comms with other SPI slaves do not need to call `SPI.begin()` if `flash.begin()` has already been called first in the user's code.
- Sped up `_beginSPI()`. Code in `_beginSPI()` instantiates the SPI bus if another SPI comms library has shut it down.
- Added function allowing setting SPI clock speeds - call the function `flash.setClock(uint32_t clockSpeed)` straight after `begin()`.
- Made `_beginSPI()` & `_nextByte()` shorter and faster.
- Replaced all calls to `SPI.transfer()` with `xfer()` to make the code more human readable and to enable simplicity when switching platforms.
- Added the ability to change Chip Erase wait times depending on the chip (supported chips only).
- Don't need to `#include <SPI.h>` in user code anymore. Just `#include<SPIFlash.h>` will do. Examples are now updated.
- Now supports & uses `SPI.transfer(*buf, count)` along with the standard `SPI.transfer()`, speeding up the read/write of anything larger than an byte (AVR Boards only)
--> Reduces the program storage space in the uC's flash (AVR Boards only)

<hr>

## Version 2.4.0

#### Release date 11.09.2016

###### Bugs Squashed:
- Fixed bug preventing writing to Address 0x00
- Fixed bug in `_notPrevWritten()` which did did not perform a thorough enough check to see if a location had been previously written to.
- Fixed errorchecking bug - it now works for all data types - not just byte/char as previously.

###### Enhancements & Optimizations:
- Added a function 'error()' to enable users to check for errors generated at any point in their program.
- Optimized writePage() so it doesn't depend on other functions and so runs faster than before.
- Diagnostics.ino now outputs time taken for each function as a part of its and provides additional diagnostic data.
- Now have a common set of private functions:
	* `_prep()`
	* `_beginSPI()`
	* `_nextByte()`
	* `_endSPI()`

	to replace

	* `_prepWrite()`
	* `_prepRead()`
	* `_beginRead()`
	* `_readNextByte()`
	* `_beginWrite()`
	* `_writeNextByte()` &
	* `_endProcess()`
- Changed the way `_addressCheck()` works. It now checks all addresses involved in writing the data rather than one address block at a time and returns the correct address to write to in case overflow is enabled. Also, this function is now built into `_prep()`.
- Reading and writing using page numbers + offset has been optimised to be faster than before.
- Optimized the way address and error checking is done so its more efficient and uses few system resources and runs faster.
- Using this library with an ESP8266 board defaults to using GPIO15 as the Slave Select - unless something different is explicitly specified in the constructor.

<hr>

## Version 2.3.1

#### Release date 19.06.2016

- W25Q256FV support added. (Thanks [@Stanislav-Povolotsky](https://github.com/Marzogh/SPIMemory/pull/26)!)
- Cleaned up redundant code in TestFlash.ino and SPIFlash.h

<hr>

## Version 2.3.0

#### Release date 04.06.2016

- ESP8266 compatibility added
- Compatible with Arduino Fio and Micro
- Now compatible with Arduino IDE v1.6.9
- Compatible with Arduino-Makefile. (Thanks [@rnestler](https://github.com/Marzogh/SPIMemory/pull/21) !)

<hr>

## Version 2.2.0

#### Release date 24.11.2015

- When `#RUNDIAGNOSTIC` is uncommented, the `_troubleshoot()` function is now optimised for different µCs
- Added the ability to check if the address has been previously written to before initiating a write
	operation.
- Added a `sizeofStr()` function to get sizes of String objects, to use with the `getAddress()` function
- Fixed a bug with `getAddress()`
- Added the ability get the chip's name via `getChipName()`
- `Diagnostics.ino` has been made more and efficient and provides a cleaner Serial output
- Added `getAddressEx.ino` to show how `getAdress()` works.

<hr>

## Version 2.1.1

#### Release date 24.10.2015

- Fixed bugs that prevented the following functions from working properly

	* `powerDown()`
	* `powerUp()`
	* `suspendProg()`
	* `resumeProg()`

<hr>

## Version 2.1.0

#### Release date 18.10.2015

- Arduino Due compatible - refer to wiki for further details
- Fixed bug with write/readByteArray
- Added write/readCharArray
- Added a proper error checking function that gets called when #ifdef RUNDIAGNOSTIC is uncommented in SPIFlash.cpp.
	This function returns a verbose error message to the Serial console instead of the terse error codes of the previous version.
- The following functions have been changed to enable bug fixes and uniformity in coding style.

	* `writeBytes()`
	* `readBytes()`

	They have been replaced with

	* `readByteArray()`
	* `writeByteArray()`

	respectively

<hr>

## Version 2.0.0

#### Release date 12.10.2015

- Sped up all functions atleast 25x
- Compatible with ATTiny85
- All Read/Write/Erase functions can now take either (page number & offset) or (address) as arguments (Except `readPage()` & `printPage()`)
- `getAddress()` can now return either a 32-bit address or a page number & offset - Refer to Readme.md
- Error codes explained:
		0x00	SUCCESS 		Operation successful.
		0x01	CALLBEGIN		Please make sure `begin()` has been called in `setup()`.
		0x02	UNKNOWNCHIP		Unknown chip manufacturer.
		0x03	UNKNOWNCAP		Unknown chip capacity.
		0x04	CHIPBUSY		Chip busy.
		0x05	OUTOFBOUNDS		Address out of bounds. Please check if `begin()` has been called in `setup()`.
		0x06	CANTENWRITE		Unable to `_writeEnable()`. Check wiring/chip.
		0x07	OUTOFMEM		Pagenumber outside maximum.
		0x08	OUTOFPAGE		Offset is outside page.
- The following functions are deprecated to enable compatibility with other AVR chips.

	* `_printPageBytes()`
	* `printPage()`
	* `printAllPages()`
	* `readSerialStr()`

	<sub> They can be used by uncommenting them in the SPIFlash.cpp file. However, be warned, this particular block of code has only been tested with the Arduino	IDE (1.6.5) and only with 8-bit AVR based Arduino boards and will not be supported any further.</sub>

<hr>

## Version 1.3.2

#### Release date 09.10.2015

- Added the ability to read and write String objects with a simple high level function `readStr()` & `writeStr()`
- Added the ability to `getAddress()`
- Added the ability to fastRead to every read function as the last boolean argument (defaults to FALSE)
- Changed the example code as given below:
	- Modified `TestFlash.ino` to use 25% less memory
	- `Struct_writer.ino` now writes struct to a random location on the Flash Memory chip.
	- Added instructions for real world data storage to `Struct_writer.ino`
	- `Diagnostics.ino` now provides a cleaner diagnostic readout

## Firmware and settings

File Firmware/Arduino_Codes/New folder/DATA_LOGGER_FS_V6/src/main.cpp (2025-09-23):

#include <Arduino.h>
#include <FS.h>
#include <LittleFS.h>
#include <Wire.h>
#include <Adafruit_SHT4x.h>
#include <RTClib.h>
#include "esp_sleep.h"
#include <Preferences.h>  // <<< NEW (NVS)

// ===================== CONFIG =====================
#define SDA_PIN        4
#define SCL_PIN        5
#define LED_PIN       12
#define MODE_BTN_PIN  22        // Hold LOW at boot for Dump/Data Retrieval mode
#define DEFAULT_SLEEP_SECONDS 30   // default 7.5min if no NVS value
static const char *ROOT = "/logs";

// ---- Battery sense (SET THESE) ----
#define VBAT_PIN      1
static const float VBAT_RTOP = 100000.0f;  // ohms
static const float VBAT_RBOT = 390000.0f;  // ohms
//static const float VBAT_CAL  = 1.19972f;    // tweak after DMM comparison
static const float VBAT_CAL  = 1.231f;    // tweak after DMM comparison
// ==================================================

// --- Devices ---
Adafruit_SHT4x sht4;
RTC_PCF8523 rtc;
bool rtc_ok = false;

// --- NVS (Preferences) ---
Preferences prefs;
static const char* NVS_NS = "logger";
static const char* NVS_KEY_INTERVAL = "int_s";

// --- RTC-deep sleep boot counter (in RTC RAM) ---
RTC_DATA_ATTR uint32_t wakeCount = 0;

// --- Current targets for logger mode ---
String currentDate, currentFolder, currentCsv;

// --- Active logging interval (loaded from NVS) ---
uint32_t sleepSeconds = DEFAULT_SLEEP_SECONDS;

// ---------- Small utils ----------
static inline void blinkOnce(uint16_t ms = 200) {
  pinMode(LED_PIN, OUTPUT);
  digitalWrite(LED_PIN, HIGH);
  delay(ms);
  digitalWrite(LED_PIN, LOW);
}

static inline void zp2(Print& p, int v) { if (v < 10) p.print('0'); p.print(v); }

// ---------- NVS helpers ----------
void loadIntervalFromNVS() {
  if (!prefs.begin(NVS_NS, /*readOnly=*/true)) {
    Serial.println("⚠️ NVS open(ro) failed, using default interval.");
    sleepSeconds = DEFAULT_SLEEP_SECONDS;
    return;
  }
  uint32_t val = prefs.getUInt(NVS_KEY_INTERVAL, DEFAULT_SLEEP_SECONDS);
  prefs.end();
  // sanity clamp (30s .. 24h)
  if (val < 30) val = 30;
  if (val > 86400UL) val = 86400UL;
  sleepSeconds = val;
}

bool storeIntervalToNVS(uint32_t val) {
  if (!prefs.begin(NVS_NS, /*readOnly=*/false)) {
    return false;
  }
  prefs.putUInt(NVS_KEY_INTERVAL, val);
  prefs.end();
  sleepSeconds = val; // update RAM copy as well (for immediate reflection if needed)
  return true;
}

// ---------- File-system helpers for logger ----------
bool ensureTodayTargets(const String &dateStr) {
  LittleFS.mkdir("/logs");
  String dayFolder = String(ROOT) + "/" + dateStr;
  LittleFS.mkdir(dayFolder);

  String csvPath = dayFolder + "/" + dateStr + ".csv";

  bool needHeader = !LittleFS.exists(csvPath);
  if (!needHeader) {
    File f = LittleFS.open(csvPath, FILE_READ);
    if (!f || f.size() == 0) needHeader = true;
    if (f) f.close();
  }
  if (needHeader) {
    File f = LittleFS.open(csvPath, FILE_WRITE);
    if (!f) {
      Serial.println("Failed to create CSV for header");
      return false;
    }
    f.println("time,temperature,humidity,vbat_mV");
    f.close();
  }

  currentDate   = dateStr;
  currentFolder = dayFolder;
  currentCsv    = csvPath;
  return true;
}

bool appendCsv(const String &csvLine) {
  File f = LittleFS.open(currentCsv, FILE_APPEND);
  if (!f) {
    f = LittleFS.open(currentCsv, FILE_WRITE);
    if (!f) {
      Serial.println("Failed to open CSV (append/create)");
      return false;
    }
  }
  f.println(csvLine);
  f.flush();
  f.close();
  return true;
}

// ---------- Sensor/RTC helpers ----------
bool initI2CAndDevices() {
  Wire.begin(SDA_PIN, SCL_PIN);
  Wire.setClock(100000); // 100 kHz

  // RTC
  rtc_ok = rtc.begin();
  if (!rtc_ok) {
    Serial.println("❌ Couldn't find PCF8523 RTC on I2C bus!");
  } else {
    if (!rtc.initialized() || rtc.lostPower()) {
      Serial.println("⏱️ RTC not initialized or lost power. Setting to compile time.");
      rtc.adjust(DateTime(F(__DATE__), F(__TIME__)));
    }
    rtc.start();
  }

  // SHT4x
  if (!sht4.begin(&Wire)) {
    Serial.println("❌ Failed to find SHT4x. Check wiring.");
    return false;
  }
  sht4.setPrecision(SHT4X_HIGH_PRECISION);
  sht4.setHeater(SHT4X_NO_HEATER);

  // VBAT ADC pin prepare
  pinMode(VBAT_PIN, INPUT);
  #if defined(ARDUINO_ARCH_ESP32)

    //analogSetPinAttenuation(VBAT_PIN, ADC_11db);
  #endif

  return true;
}

DateTime readNow() {
  return rtc_ok ? rtc.now() : DateTime(F(__DATE__), F(__TIME__));
}

String dateToStr(const DateTime& dt) {
  String s;
  s.reserve(10);
  s += String(dt.year()); s += '-';
  if (dt.month() < 10) s += '0'; s += String(dt.month()); s += '-';
  if (dt.day()   < 10) s += '0'; s += String(dt.day());
  return s;
}

String timeToStr(const DateTime& dt) {
  String s;
  s.reserve(8);
  if (dt.hour()   < 10) s += '0'; s += String(dt.hour());   s += ':';
  if (dt.minute() < 10) s += '0'; s += String(dt.minute()); s += ':';
  if (dt.second() < 10) s += '0'; s += String(dt.second());
  return s;
}

bool readSHT(float &tC, float &rh) {
  sensors_event_t humidity, temp;
  if (!sht4.getEvent(&humidity, &temp)) return false;
  tC = temp.temperature;
  rh = humidity.relative_humidity;
  return true;
}

// ----------- VBAT measurement helpers -----------
uint32_t readVBAT_mV() {
  const uint8_t N = 5;
  uint32_t acc_mV = 0;

  for (uint8_t i = 0; i < N; i++) {
   // #if defined(ARDUINO_ARCH_ESP32)
     // uint32_t mv = analogReadMilliVolts(VBAT_PIN);
    //#else
      uint32_t raw = analogRead(VBAT_PIN);
      uint32_t mv = (raw * 3300UL) / 4095UL;
   // #endif
    acc_mV += mv;
    delay(50);
  }
  float pin_mV = acc_mV / float(N);

  float gain = (VBAT_RTOP + VBAT_RBOT) / VBAT_RBOT;
  float vbat_mV = pin_mV * gain * VBAT_CAL;

  if (vbat_mV < 0) vbat_mV = 0;
  if (vbat_mV > 100000.0f) vbat_mV = 100000.0f;

  return (uint32_t)(vbat_mV + 0.5f);
}

// ===================================================
// ===============  DUMP MODE (Protocol) =============
// Commands: HELLO | LIST | GET YYYY-MM-DD | BYE
// PLUS: SETTIME YYYY-MM-DD HH:MM:SS | TIME? | SENSE? | VBAT?
//       INTERVAL? | SETINTERVAL <sec>
// ===================================================

static String readLineWithTimeout(uint32_t timeout_ms = 2000) {
  String line;
  uint32_t start = millis();
  while (millis() - start < timeout_ms) {
    while (Serial.available()) {
      char c = (char)Serial.read();
      if (c == '\r') continue;
      if (c == '\n') return line;
      line += c;
    }
    delay(1);
  }
  return "";
}

static uint32_t crc32_update(uint32_t crc, const uint8_t* data, size_t len) {
  crc = ~crc;
  for (size_t i = 0; i < len; i++) {
    crc ^= data[i];
    for (uint8_t k = 0; k < 8; k++) {
      uint32_t mask = -(crc & 1U);
      crc = (crc >> 1) ^ (0xEDB88320U & mask);
    }
  }
  return ~crc;
}

static String buildLogPath(const String& date) {
  if (date.length() != 10 || date.charAt(4) != '-' || date.charAt(7) != '-') return "";
  for (uint8_t i : {0,1,2,3,5,6,8,9}) if (!isDigit(date[i])) return "";
  return String(ROOT) + "/" + date + "/" + date + ".csv";
}

static uint32_t countRowsQuick(File& f) {
  const size_t BUFSZ = 1024;
  static uint8_t buf[BUFSZ];
  uint32_t rows = 0;
  f.seek(0, SeekSet);
  while (true) {
    int n = f.read(buf, BUFSZ);
    if (n <= 0) break;
    for (int i = 0; i < n; i++) if (buf[i] == '\n') rows++;
  }
  f.seek(0, SeekSet);
  return rows;
}

static void listDatesProtocol() {
  File root = LittleFS.open(ROOT, "r");
  if (!root || !root.isDirectory()) {
    Serial.println("DATES 0");
    Serial.println("END");
    return;
  }

  uint32_t count = 0;
  for (File e = root.openNextFile(); e; e = root.openNextFile()) {
    if (e.isDirectory()) count++;
  }

  Serial.print("DATES "); Serial.println(count);

  root = LittleFS.open(ROOT, "r");
  for (File e = root.openNextFile(); e; e = root.openNextFile()) {
    if (!e.isDirectory()) continue;
    String full = e.name();
    String date = full;
    if (full.startsWith(String(ROOT) + "/")) date = full.substring(strlen(ROOT) + 1);
    if (date.endsWith("/")) date.remove(date.length() - 1);
    Serial.println(date);
  }
  Serial.println("END");
}

static void handleGetDate(const String& date) {
  String path = buildLogPath(date);
  if (path == "") {
    Serial.println("ERR code=BAD_DATE msg=\"format YYYY-MM-DD\"");
    return;
  }
  if (!LittleFS.exists(path)) {
    Serial.print("ERR code=NOT_FOUND msg=\"no file for ");
    Serial.print(date);
    Serial.println("\"");
    return;
  }

  File f = LittleFS.open(path, "r");
  if (!f) {
    Serial.println("ERR code=IO msg=\"open failed\"");
    return;
  }

  size_t size = f.size();
  uint32_t rows = countRowsQuick(f);

  Serial.print("OK SIZE=");  Serial.print(size);
  Serial.print(" ROWS=");    Serial.print(rows);
  Serial.print(" PATH=");    Serial.println(path);

  Serial.println("DATA");

  const size_t BUFSZ = 1024;
  static uint8_t buf[BUFSZ];
  uint32_t crc = 0x00000000;
  size_t remaining = size;

  while (remaining > 0) {
    size_t chunk = remaining > BUFSZ ? BUFSZ : remaining;
    int n = f.read(buf, chunk);
    if (n <= 0) break;
    Serial.write(buf, n);
    crc = crc32_update(crc, buf, n);
    remaining -= n;
  }
  f.close();

  Serial.println();
  Serial.println("END");

  char hex[9];
  snprintf(hex, sizeof(hex), "%08lX", (unsigned long)crc);
  Serial.print("CRC32="); Serial.println(hex);
}

// Parse "YYYY-MM-DD HH:MM:SS" into DateTime; return true if ok
static bool parseDateTime(const String& s, DateTime& out) {
  if (s.length() != 19) return false;
  // 0123456789012345678
  // YYYY-MM-DD HH:MM:SS
  if (s.charAt(4) != '-' || s.charAt(7) != '-' || s.charAt(10) != ' ' ||
      s.charAt(13) != ':' || s.charAt(16) != ':') return false;
  for (uint8_t i : {0,1,2,3,5,6,8,9,11,12,14,15,17,18})
    if (!isDigit(s[i])) return false;

  int yr = s.substring(0,4).toInt();
  int mo = s.substring(5,7).toInt();
  int dy = s.substring(8,10).toInt();
  int hh = s.substring(11,13).toInt();
  int mm = s.substring(14,16).toInt();
  int ss = s.substring(17,19).toInt();

  if (yr < 2000 || yr > 2099) return false;
  if (mo < 1 || mo > 12) return false;
  if (dy < 1 || dy > 31) return false;
  if (hh < 0 || hh > 23) return false;
  if (mm < 0 || mm > 59) return false;
  if (ss < 0 || ss > 59) return false;

  out = DateTime(yr, mo, dy, hh, mm, ss);
  return true;
}

// Dump/Data Retrieval server (push-button entry only)
void runDataRetrievalMode() {
  // Bring up I2C + devices so commands work in dump mode
  Wire.begin(SDA_PIN, SCL_PIN);
  Wire.setClock(100000);

  // RTC init (okay if missing)
  rtc_ok = rtc.begin();
  if (rtc_ok) rtc.start();

  // Try SHT4x init (okay if missing; we'll retry on demand)
  bool sht_ok = sht4.begin(&Wire);
  if (sht_ok) {
    sht4.setPrecision(SHT4X_HIGH_PRECISION);
    sht4.setHeater(SHT4X_NO_HEATER);
  }

  // Prepare VBAT ADC in server mode too
  pinMode(VBAT_PIN, INPUT);
  #if defined(ARDUINO_ARCH_ESP32)
    //analogSetPinAttenuation(VBAT_PIN, ADC_11db);
  #endif

  bool led = false;
  uint32_t lastBlink = 0;

  Serial.println("OK v=1 caps=GET,LIST,CRC,SETTIME,TIME?,SENSE?,VBAT?,INTERVAL?,SETINTERVAL"); // capability banner

  while (true) {
    // non-blocking blink (250 ms on / 750 ms off)
    uint32_t now = millis();
    if (now - lastBlink >= (led ? 250u : 750u)) {
      led = !led;
      digitalWrite(LED_PIN, led ? HIGH : LOW);
      lastBlink = now;
    }

    String line = readLineWithTimeout(100);
    if (line.length() == 0) continue;
    line.trim();

    if (line.startsWith("HELLO")) {
      Serial.println("OK v=1 caps=GET,LIST,CRC,SETTIME,TIME?,SENSE?,VBAT?,INTERVAL?,SETINTERVAL");
    } else if (line == "LIST") {
      listDatesProtocol();
    } else if (line.startsWith("GET ")) {
      String date = line.substring(4);
      date.trim();
      handleGetDate(date);
    } else if (line == "BYE") {
      Serial.println("OK bye");
      // stay in server
    }
    else if (line == "TIME?") {
      if (!rtc_ok) {
        Serial.println("ERR code=RTC msg=\"not found\"");
      } else {
        DateTime nowdt = rtc.now();
        Serial.print("OK ");
        Serial.print(nowdt.year()); Serial.print('-');
        if (nowdt.month()<10) Serial.print('0'); Serial.print(nowdt.month()); Serial.print('-');
        if (nowdt.day()<10)   Serial.print('0'); Serial.print(nowdt.day());   Serial.print(' ');
        if (nowdt.hour()<10)  Serial.print('0'); Serial.print(nowdt.hour());  Serial.print(':');
        if (nowdt.minute()<10)Serial.print('0'); Serial.print(nowdt.minute());Serial.print(':');
        if (nowdt.second()<10)Serial.print('0'); Serial.println(nowdt.second());
      }
    }
    else if (line.startsWith("SETTIME ")) {
      String payload = line.substring(8);
      payload.trim();

      if (!rtc_ok) {
        Serial.println("ERR code=RTC msg=\"not found\"");
        continue;
      }

      DateTime dt;
      if (!parseDateTime(payload, dt)) {
        Serial.println("ERR code=BAD_DT msg=\"use SETTIME YYYY-MM-DD HH:MM:SS\"");
        continue;
      }

      rtc.adjust(dt);
      rtc.start();
      Serial.print("OK set ");
      Serial.print(dt.year()); Serial.print('-');
      if (dt.month()<10) Serial.print('0'); Serial.print(dt.month()); Serial.print('-');
      if (dt.day()<10)   Serial.print('0'); Serial.print(dt.day());   Serial.print(' ');
      if (dt.hour()<10)  Serial.print('0'); Serial.print(dt.hour());  Serial.print(':');
      if (dt.minute()<10)Serial.print('0'); Serial.print(dt.minute());Serial.print(':');
      if (dt.second()<10)Serial.print('0'); Serial.println(dt.second());
    }
    // ===== SENSE? -> one SHT4x reading + battery voltage =====
    else if (line == "SENSE?") {
      // (Re)try init if needed
      if (!sht_ok) {
        sht_ok = sht4.begin(&Wire);
        if (sht_ok) {
          sht4.setPrecision(SHT4X_HIGH_PRECISION);
          sht4.setHeater(SHT4X_NO_HEATER);
        }
      }
      if (!sht_ok) {
        Serial.println("ERR code=SHT4X msg=\"not found\"");
        continue;
      }
      sensors_event_t humidity, temp;
      if (!sht4.getEvent(&humidity, &temp)) {
        Serial.println("ERR code=SHT4X msg=\"read failed\"");
        continue;
      }
      uint32_t mv = readVBAT_mV();
      Serial.print("OK T=");
      Serial.print(temp.temperature, 2);
      Serial.print("C RH=");
      Serial.print(humidity.relative_humidity, 2);
      Serial.print("% VBAT=");
      Serial.print(mv);
      Serial.println("mV");
    }
    // ===== VBAT? -> battery voltage only =====
    else if (line == "VBAT?") {
      uint32_t mv = readVBAT_mV();
      Serial.print("OK VBAT=");
      Serial.print(mv);
      Serial.println("mV");
    }
    // ===== INTERVAL? -> current logging interval from NVS =====
    else if (line == "INTERVAL?") {
      // Ensure we report the latest value (reload)
      loadIntervalFromNVS();
      Serial.print("OK INTERVAL=");
      Serial.println(sleepSeconds);
    }
    // ===== SETINTERVAL <seconds> -> store in NVS =====
    else if (line.startsWith("SETINTERVAL ")) {
      String payload = line.substring(12);
      payload.trim();
      if (payload.length() == 0) {
        Serial.println("ERR code=BAD_ARG msg=\"use SETINTERVAL <seconds>\"");
        continue;
      }
      uint32_t val = (uint32_t) payload.toInt();
      if (val < 30) val = 30;
      if (val > 86400UL) val = 86400UL; // clamp to 24h
      if (!storeIntervalToNVS(val)) {
        Serial.println("ERR code=NVS msg=\"write failed\"");
      } else {
        Serial.print("OK set INTERVAL=");
        Serial.println(val);
      }
    }
    else {
      Serial.println("ERR code=UNKNOWN msg=\"use HELLO|LIST|GET YYYY-MM-DD|SETTIME YYYY-MM-DD HH:MM:SS|TIME?|SENSE?|VBAT?|INTERVAL?|SETINTERVAL|BYE\"");
    }
  }
}

// ===================================================
// ==================  LOGGING MODE  =================
// ===================================================
void runLoggingMode() {
  esp_sleep_wakeup_cause_t wakeup_reason = esp_sleep_get_wakeup_cause();
  Serial.println("\n==============================");
  if (wakeup_reason == ESP_SLEEP_WAKEUP_TIMER) {
    Serial.println("🔋 Woke up from deep sleep (timer).");
  } else {
    Serial.println("⚡ First boot or external reset.");
  }
  Serial.printf("Wake count: %lu\n", (unsigned long)++wakeCount);

  blinkOnce(150);

  // Load logging interval from NVS (with sane clamps)
  loadIntervalFromNVS();
  Serial.print("⏲️ Logging interval (s): ");
  Serial.println(sleepSeconds);

  bool dev_ok = initI2CAndDevices();

  DateTime now = readNow();
  String d = dateToStr(now);
  String t = timeToStr(now);

  if (!ensureTodayTargets(d)) {
    Serial.println("⚠️ Could not ensure today's CSV.");
  }

  float tC = NAN, rh = NAN;
  bool got = dev_ok && readSHT(tC, rh);
  if (!got) {
    Serial.println("❌ SHT4x read failed! Writing NaN placeholders.");
  }

  uint32_t vbat_mV = readVBAT_mV();

  String line = t + "," + String(tC, 2) + "," + String(rh, 2) + "," + String(vbat_mV);
  if (!appendCsv(line)) {
    Serial.println("Append failed");
  } else {
    Serial.print("Logged -> ");
    Serial.println(line);
    Serial.println("File: " + currentCsv);
  }

  Wire.end();
  pinMode(SDA_PIN, INPUT);
  pinMode(SCL_PIN, INPUT);
  digitalWrite(LED_PIN, LOW);

  // Sleep for configured interval
  esp_sleep_enable_timer_wakeup((uint64_t)sleepSeconds * 1000000ULL);
  Serial.print("🌙 Going to deep sleep for ");
  Serial.print(sleepSeconds);
  Serial.println(" s...");
  Serial.flush();
  delay(20);
  esp_deep_sleep_start();
}

// ===================================================
// ================= Arduino entry ===================
// ===================================================
void setup() {
  pinMode(MODE_BTN_PIN, INPUT_PULLUP);
  pinMode(LED_PIN, OUTPUT);
  digitalWrite(LED_PIN, LOW);

  Serial.begin(115200);
  delay(100);

  if (!LittleFS.begin()) {
    Serial.println("⚠️ LittleFS mount failed. Attempting to format...");
    if (!LittleFS.begin(true)) {
      Serial.println("❌ LittleFS mount/format failed. Retrieval/logging to FS disabled.");
    }
  }

  // Boot-time mode select (hold MODE button low to enter server)
  if (digitalRead(MODE_BTN_PIN) == LOW) {
    uint32_t t0 = millis();
    while (digitalRead(MODE_BTN_PIN) == LOW && millis() - t0 < 1000) {
      delay(5);
    }
    if (millis() - t0 >= 400) {
      runDataRetrievalMode(); // never returns
    }
  }

  runLoggingMode(); // deep-sleeps at end
}

void loop() { }

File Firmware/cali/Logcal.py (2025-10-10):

# sht45_logger_gui.py
# Simple Tkinter GUI to read "DATA,<millis>,<temp_C>,<rh_%>" lines from your firmware
# and append "timestamp,temp_C,rh_pct" to a daily CSV.

import tkinter as tk
from tkinter import ttk, messagebox
from datetime import datetime, date
import csv
import threading
import queue
import time
import os

import serial
import serial.tools.list_ports

BAUD = 115200

class SHT45GUI:
    def __init__(self, root):
        self.root = root
        root.title("SHT45 Serial Logger")

        # State
        self.ser = None
        self.reader_thread = None
        self.reader_stop = threading.Event()
        self.q = queue.Queue()
        self.streaming = False
        self.current_csv_date = None
        self.csv_path = None

        # --- Top frame: connection ---
        frm_top = ttk.Frame(root, padding=8)
        frm_top.grid(row=0, column=0, sticky="ew")
        frm_top.columnconfigure(3, weight=1)

        ttk.Label(frm_top, text="Port:").grid(row=0, column=0, sticky="w")
        self.port_combo = ttk.Combobox(frm_top, width=18, state="readonly", values=self.list_ports())
        self.port_combo.grid(row=0, column=1, sticky="w", padx=(4, 8))

        self.refresh_btn = ttk.Button(frm_top, text="Refresh", command=self.refresh_ports)
        self.refresh_btn.grid(row=0, column=2, sticky="w")

        self.connect_btn = ttk.Button(frm_top, text="Connect", command=self.connect)
        self.connect_btn.grid(row=0, column=3, sticky="e")

        # --- Middle frame: controls & display ---
        frm_mid = ttk.Frame(root, padding=(8, 0, 8, 8))
        frm_mid.grid(row=1, column=0, sticky="ew")
        frm_mid.columnconfigure(4, weight=1)

        ttk.Label(frm_mid, text="Interval (ms):").grid(row=0, column=0, sticky="w")
        self.interval_var = tk.StringVar(value="5000")
        self.interval_entry = ttk.Entry(frm_mid, width=10, textvariable=self.interval_var)
        self.interval_entry.grid(row=0, column=1, sticky="w", padx=(4, 16))

        self.start_btn = ttk.Button(frm_mid, text="Start", command=self.start_stream, state="disabled")
        self.start_btn.grid(row=0, column=2, padx=4)
        self.stop_btn = ttk.Button(frm_mid, text="Stop", command=self.stop_stream, state="disabled")
        self.stop_btn.grid(row=0, column=3, padx=4)

        # Live readouts
        box = ttk.LabelFrame(frm_mid, text="Latest Reading", padding=8)
        box.grid(row=1, column=0, columnspan=5, sticky="ew", pady=(8, 0))
        for i in range(6):
            box.columnconfigure(i, weight=1)

        ttk.Label(box, text="System Time:").grid(row=0, column=0, sticky="e")
        self.lbl_time = ttk.Label(box, text="—")
        self.lbl_time.grid(row=0, column=1, sticky="w")

        ttk.Label(box, text="Temp (°C):").grid(row=0, column=2, sticky="e")
        self.lbl_temp = ttk.Label(box, text="—")
        self.lbl_temp.grid(row=0, column=3, sticky="w")

        ttk.Label(box, text="Humidity (%RH):").grid(row=0, column=4, sticky="e")
        self.lbl_rh = ttk.Label(box, text="—")
        self.lbl_rh.grid(row=0, column=5, sticky="w")

        # Status bar
        self.status = tk.StringVar(value="Disconnected")
        ttk.Label(root, textvariable=self.status, anchor="w", padding=(8, 4)).grid(row=2, column=0, sticky="ew")

        # Start UI polling loop
        self.root.after(100, self.poll_queue)

        # Handle window close
        self.root.protocol("WM_DELETE_WINDOW", self.on_close)

    # ---------- Serial / ports ----------
    def list_ports(self):
        ports = [p.device for p in serial.tools.list_ports.comports()]
        return ports

    def refresh_ports(self):
        self.port_combo["values"] = self.list_ports()
        if not self.port_combo.get() and self.port_combo["values"]:
            self.port_combo.current(0)

    def connect(self):
        if self.ser and self.ser.is_open:
            # Disconnect
            self.stop_reader_thread()
            try:
                self.ser.close()
            except Exception:
                pass
            self.ser = None
            self.connect_btn.config(text="Connect")
            self.start_btn.config(state="disabled")
            self.stop_btn.config(state="disabled")
            self.status.set("Disconnected")
            return

        port = self.port_combo.get()
        if not port:
            messagebox.showwarning("Select Port", "Please select a COM port.")
            return
        try:
            self.ser = serial.Serial(port, BAUD, timeout=0.1)
            self.status.set(f"Connected: {port} @ {BAUD}")
            self.connect_btn.config(text="Disconnect")
            self.start_btn.config(state="normal")
            self.stop_btn.config(state="disabled")
            self.start_reader_thread()
        except Exception as e:
            self.ser = None
            messagebox.showerror("Connection failed", str(e))
            self.status.set("Disconnected")

    # ---------- Reader thread ----------
    def start_reader_thread(self):
        self.reader_stop.clear()
        self.reader_thread = threading.Thread(target=self.reader_loop, daemon=True)
        self.reader_thread.start()

    def stop_reader_thread(self):
        self.reader_stop.set()
        if self.reader_thread and self.reader_thread.is_alive():
            self.reader_thread.join(timeout=1.0)
        self.reader_thread = None

    def reader_loop(self):
        buf = bytearray()
        while not self.reader_stop.is_set():
            try:
                if self.ser and self.ser.is_open:
                    chunk = self.ser.read(256)
                    if chunk:
                        buf.extend(chunk)
                        while b"\n" in buf:
                            line, _, buf = buf.partition(b"\n")
                            try:
                                s = line.decode("utf-8", errors="ignore").strip("\r")
                            except Exception:
                                s = ""
                            if s:
                                self.q.put(("serial_line", s))
                else:
                    time.sleep(0.2)
            except Exception as e:
                self.q.put(("error", f"Serial error: {e}"))
                time.sleep(0.5)

    # ---------- Commands ----------
    def send_line(self, text):
        if not (self.ser and self.ser.is_open):
            return
        try:
            self.ser.write((text.strip() + "\n").encode("utf-8"))
        except Exception as e:
            self.q.put(("error", f"Write failed: {e}"))
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

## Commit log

2025-07-26 Add Datasheets TEMP Sensor
2025-08-30 Hardware finalized
    [2025-08-23.csv, 2025-08-24.csv, 2025-08-25.csv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]
2025-09-26 2025-09-26-Placement ok
    [Battery_Protection.SchDoc, Logger_PCB.PcbDoc, Logger_PCB_1.PcbDoc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]
2025-09-29 2025-09-30 Layout Completed
    [Logger_PCB_6.PcbDoc]
2025-09-29 2025-09-30 Layout ok
    [Logger_PCB_6.PcbDoc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]
2025-10-08 2025-10-08 Layout ok
    [2025-09-04.csv, 2025-09-05.csv, 2025-09-06.csv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]
2025-10-10 2025-10-10 Calibration gui ok
    [Firmware_Requiremnts.xlsx, sht45_log_2025-10-10.csv]
